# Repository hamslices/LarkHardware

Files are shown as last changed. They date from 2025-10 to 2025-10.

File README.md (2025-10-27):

# Lark - Thermal Print Engine Controller

**Version:** 01.00.01  
**Author:** HamSlices  
**License:** CERN Open Hardware Licence v2 - Strongly Reciprocal  

## This Design Still Needs Bench Tested, WIP, waiting on boards (10/27/2025)

This repository contains the complete hardware design files for the Lark, a controller board specifically designed for the **FUJITSU FTP-68EMCL112-R** 8-inch thermal print mechanism.

The goal of this project is to provide a fully open-source hardware solution for driving this excellent thermal printer, suitable for custom projects, prototyping, or integration into larger systems.

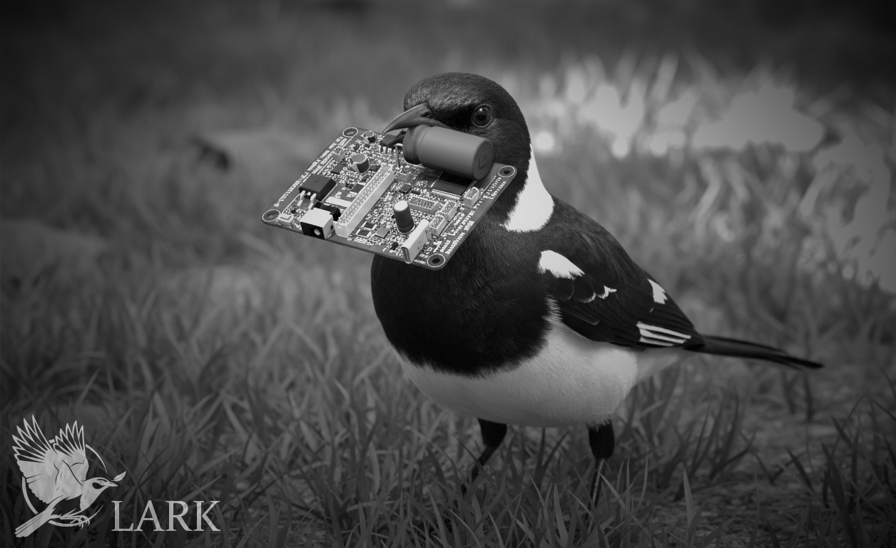
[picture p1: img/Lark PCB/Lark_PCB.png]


## Repository Contents

This repository includes all the necessary resources to build and case the hardware:

*   **Lark Controller Board**: The core of the project, designed to drive the Fujitsu thermal printer.
*   **Front I/O Board**: A separate PCB for user-facing controls and connectors.
*   **STLink-V2 Adapter**: A small adapter PCB to easily connect an STLink-V2 for programming and debugging.
*   **3D Printable Enclosures**: Includes custom cases for the Lark board, the Front I/O board, and a test enclosure for the print mechanism itself.

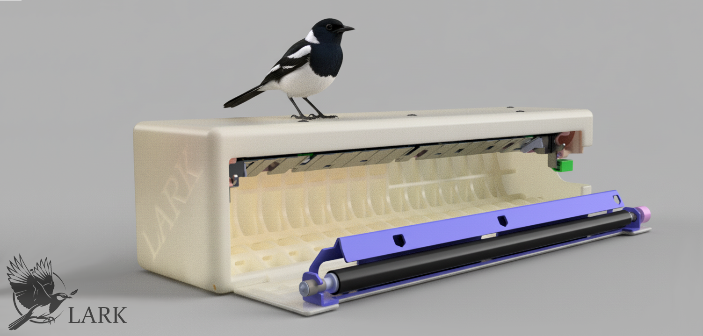
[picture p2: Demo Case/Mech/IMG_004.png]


## Directory Structure

Here is a breakdown of the repository's structure:

*   **`/3D`**: Contains 3D models of the various hardware components and enclosures.
*   **`/CubeMX_Lark`**: The STM32CubeMX project file (`.ioc`) for configuring the Lark's microcontroller.
*   **`/Demo Case`**: Files for the 3D printable enclosures for the Lark board, Front I/O, and the print mechanism.
*   **`/img`**: Images, screenshots, and logos related to the project.
*   **`/Kicad Project Files`**: The source files for all hardware designed in KiCad.
    *   **`/FrontIO`**: KiCad project for the Front I/O board.
    *   **`/Lark`**: KiCad project for the main Lark controller board.
    *   **`/STLink_adapter`**: KiCad project for the STLink-V2 adapter.
*   **`/lib`**: Custom KiCad schematic symbols and PCB footprints created for this project.
*   **`/Production_Files`**: Ready-to-manufacture files (Gerbers and BOMs) for all PCBs.

## Getting Started

To work with the hardware design files, you will need to install the latest version of [KiCad](https://www.kicad.org/).

The 3D models are provided in STEP format and can be viewed with any compatible software.

The production files located in the `/Production_Files` directory are ready to be sent to a PCB manufacturer for fabrication and assembly.

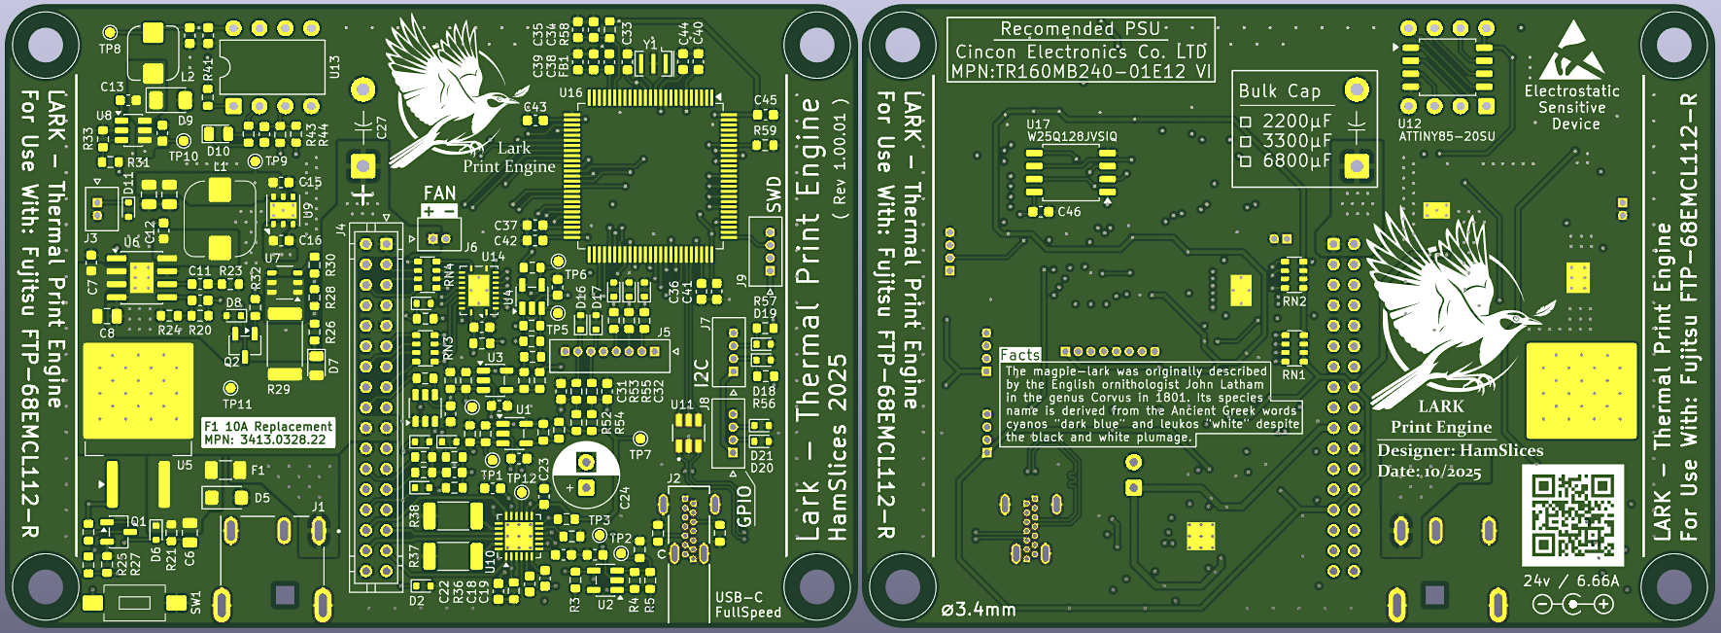
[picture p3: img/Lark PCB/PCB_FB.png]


## Software / Firmware

The firmware and software for the Lark controller is licensed under the **GPL v3** and is maintained in a separate repository.

## License

The hardware design files in this repository (schematics, PCB layouts, 3D models, etc.) are licensed under the **CERN Open Hardware Licence v2 - Strongly Reciprocal (CERN-OHL-S)**.

A full copy of the license is available in the `LICENSE` file in this repository. In essence, this license allows you to use, study, modify, and share the hardware designs, provided that you share any modifications or derivative works under the same license.

---
*Lark Print Engine © HamSlices 2025*

[The Lark Project](https://github.com/hamslices/The-Lark-Project)

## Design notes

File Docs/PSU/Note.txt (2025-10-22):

Durring testing I have found that the TR160MB240-01E12 VI
PSU will output 8.47A of continuous current before over current shutdown at > 8.5A

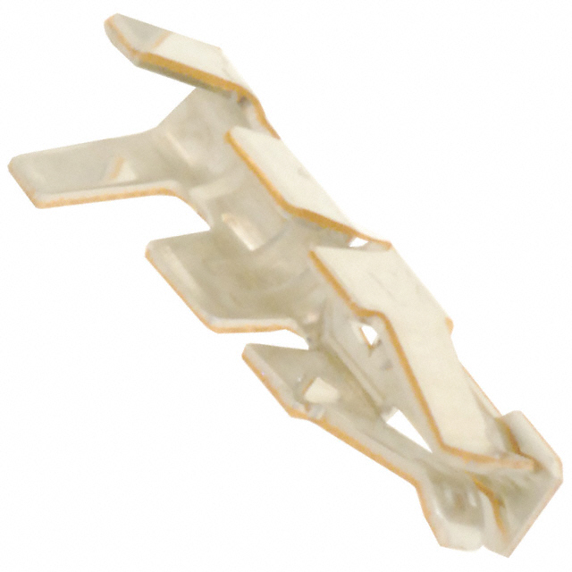
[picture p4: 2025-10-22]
Cable_Assy/img/SPHD-002T-P0.5.jpg

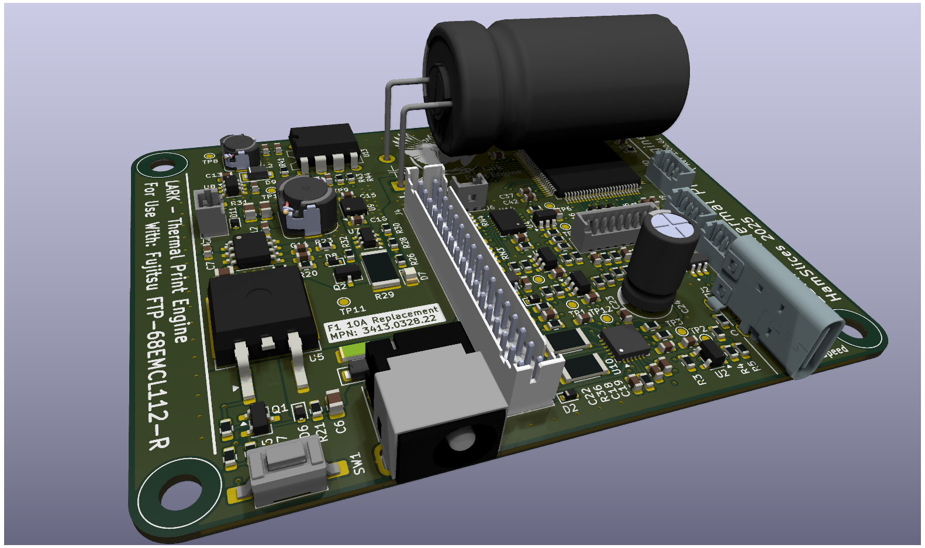
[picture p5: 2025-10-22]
img/Lark PCB/Lark_tilt.png

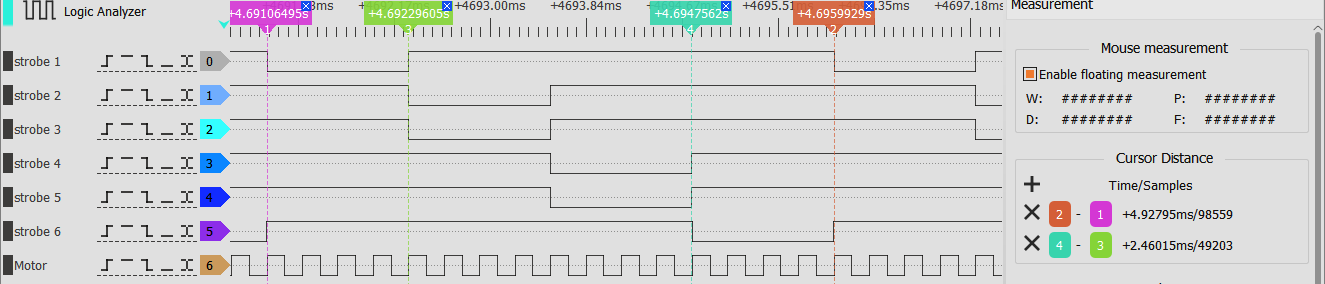
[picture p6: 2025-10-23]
img/scope/DSView-251023-170413.png

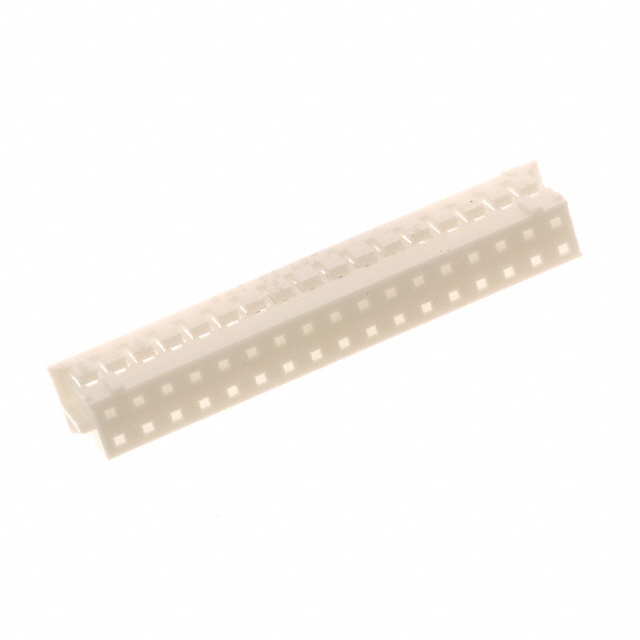
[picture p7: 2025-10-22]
Cable_Assy/img/PHDR-34VS.jpg

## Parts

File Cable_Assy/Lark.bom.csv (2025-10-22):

Id | Description | Qty | Unit | Designators | Manufacturer | MPN | Supplier | SPN
1 | Cable, 34 x 24 AWG, BK | 6 | in | W1 | CNC Tech | 3132-24-1-0500-001-1-TS | Digikey | CN119B-50-ND
2 | Connector, JST, PHDR-34VS, female, 34 pins | 2 |  | J1, X1 | JST | PHDR-34VS | Digikey | 455-1182-ND
3 | Crimp, CONN SOCKET 24-28AWG CRIMP TIN | 68 |  | J1, X1 | JST | SPHD-002T-P0.5 | Digikey | 455-1313CT-ND

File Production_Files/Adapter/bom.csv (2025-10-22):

Designator | Footprint | Quantity | Value | MPN
J1 | 0530470410 | 1 | 0530470410 | 0530470410
J2 | SFH11-PBPC-D10-ST-BK | 1 | SFH11-PBPC-D10-ST-BK | SFH11-PBPC-D10-ST-BK

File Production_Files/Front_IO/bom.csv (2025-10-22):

Designator | Footprint | Quantity | Value | MPN
D1 | QBLP600-RGB5-3164 | 1 | QBLP600-RGB5-3164 | QBLP600-RGB5-3164
J1 | 0530470810 | 1 | 0530470810 | 0530470810
J2 | 530470210 | 1 | 0530470210 | 0530470210
SW1, SW2, SW3 | TS04-66-65-BK-100-SMT | 3 | TS04-66-65-BK-100-SMT | TS04-66-65-BK-100-SMT

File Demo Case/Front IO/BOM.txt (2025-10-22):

2x,  MPN: 90116A151, URL: https://www.mcmaster.com/90116A151/

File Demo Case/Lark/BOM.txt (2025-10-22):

4x, MPN:  90116A155, URL: https://www.mcmaster.com/90116A155/

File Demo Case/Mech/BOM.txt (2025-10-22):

7x,  MPN: 90258A176, URL: https://www.mcmaster.com/90258A176/
1x, MPN: 88605K48, URL: https://www.mcmaster.com/88605K48/

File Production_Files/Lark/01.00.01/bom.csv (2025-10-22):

Designator | Footprint | Quantity | Value | MPN | DNP
C1, C12, C13, C18, C19, C2, C21, C22, C23, C25, C26, C28, C29, C3, C30, C31, C32, C33, C35, C39, C4, C40, C41, C42, C43, C44, C45, C46, C7 | C_0603 | 29 | 0.1µF | GRM188R72A104MA35J | C46
C10, C6, C8, C9 | C2012X5R1V226M125AC | 4 | 22µF | C2012X5R1V226M125AC
C11 | C_0603 | 1 | 6800pF | GRM1885C1H682JA01D
C14 | C_0603 | 1 | 4.7µF | GRM188R6YA475KE15D
C15, C16 | C_0603 | 2 | 10µF | GRM188R6YA106MA73D
C17 | C_0603 | 1 | 22µF | GRM188C61E226ME01J
C20 | C_0603 | 1 | 0.22µF | GRM188R71H224KAC4D
C24 | ECA-1VM101 | 1 | 100µF | ECA-1VM101
C27 | EEU-HD1V682_Right-Angle | 1 | 6800µF | EEU-HD1V682
C34, C38 | C_0603 | 2 | 1µF | GRM188D71H105KE01J
C36, C37 | C_0603 | 2 | 2.2µF | GRM188R61E225KA12J
C5 | C_0603 | 1 | 18pF | GRM1885C2E180JW07D
D1, D11, D12, D13, D14, D15, D16, D17, D18, D19, D2, D20, D21, D3, D4 | ESD5Z3.3T1G | 15 | ESD5Z3.3T1G | ESD5Z3.3T1G
D10, D7 | LED_0805 | 2 | LTST-C171GKT | LTST-C171GKT
D5 | SZSMF6L28AT3G | 1 | SZSMF6L28AT3G | SZSMF6L28AT3G
D6, D8 | BZT52C10T-7 | 2 | BZT52C15T-7 | BZT52C10T-7
D9 | SS26FL | 1 | SS26FL | SS26FL
F1 | 3413.0326.22 | 1 | 10A Slow Blow | 3413.0328.22
FB1 | MPZ1608S221ATA00 | 1 | 220 Ohms | MPZ1608S221ATA00
J1 | 54-00128 | 1 | 54-00128 | 54-00128
J2 | CONN_2169890002_MOL | 1 | 2169890002 | 2169890002
J3, J6 | 530470210 | 2 | 0530470210 | 0530470210
J4 | JST_PHD_B34B-PHDSS_2x17_P2.00mm_Vertical | 1 | B34B-PHDSS | B34B-PHDSS
J5 | 0530470810 | 1 | 0530470810 | 0530470810
J7, J8, J9 | 0530470410 | 3 | 0530470410 | 0530470410
L1 | CLF7045NIT-4R7N-D | 1 | 4.7µH | CLF7045NIT-4R7N-D
L2 | CLF5030NIT-150M-D | 1 | 15µH | CLF5030NIT-150M-D
Q1, Q2 | MMBT2222A-7-F | 2 | MMBT2222A-7-F | MMBT2222A-7-F
R1, R10, R16, R23, R33, R7 | R_0603 | 6 | 15kΩ | RMCF0603FG15K0
R11, R2, R5 | R_0603 | 3 | 220kΩ | RMCF0603FT220K
R12, R3 | R_0603 | 2 | 3kΩ | RMCF0603FT3K00
R13, R24, R27, R36, R4 | R_0603 | 5 | 100kΩ | RMCF0603FG100K
R14, R31 | R_0603 | 2 | 51kΩ | RMCF0603FT51K0
R15, R30, R50, R51, R6 | R_0603 | 5 | 100Ω | RMCF0603FG100R
R17, R8 | R_0603 | 2 | 24kΩ | RMCF0603FG24K0
R18 | R_0603 | 1 | 178kΩ | RMCF0603FT178K
R19, R58 | R_0603 | 2 | 0R | RMCF0603ZT0R00 | R19
R20 | R_0603 | 1 | 402kΩ | RMCF0603FT402K
R21, R26, R28, R34, R35, R41, R43, R45, R47, R52, R54, R59 | R_0603 | 12 | 10KΩ | RMCF0603FG10K0
R22 | R_0603 | 1 | 20KΩ | RMCF0603FG20K0
R25, R32, R42, R44, R46, R53, R55 | R_0603 | 7 | 1KΩ | RMCF0603FG1K00
R29 | R_2512 | 1 | 220Ω | RPCQ2512JT220R
R37, R38 | R_2010 | 2 | 400mΩ | CSRN2010FKR400
R39, R40 | R_0603 | 2 | 5.1KΩ | RMCF0603FT5K10
R48 | R_0603 | 1 | 33Ω | RMCF0603FT33R0
R49 | R_0603 | 1 | 280Ω | RMCF0603FT280R
R56, R57 | R_0603 | 2 | 4.7KΩ | RMCF0603FT4K70
R9 | R_0603 | 1 | 365kΩ | RMCF0603FT365K
RN1, RN2 | RAVF_164D | 2 | 10kΩ | RAVF164DJT10K0
RN3, RN4 | RAVF_164D | 2 | 33Ω | RAVF164DJT33R0
SW1 | PTS636 SP50 SMTR LFS | 1 | PTS636 SP50 SMTR LFS | PTS636 SP50 SMTR LFS
U1, U2, U3, U4 | SOT-23-5 | 4 | MIC7211YM5-TR | MIC7211YM5-TR
U10 | QFN-24-1EP_4x4mm_P0.5mm_EP2.75x2.75mm_ThermalVias | 1 | A4985SESTR-T | A4985SESTR-T
U11 | SOT95P280X145-6N | 1 | USBLC6-2SC6 | USBLC6-2SC6
U12 | 8-SOIC_5.3x8.2 | 1 | ATTINY85-20SU | ATTINY85-20SU | ATTINY85-20SU
U13 | DIP-8_W7.62mm | 1 | ATTINY85-20PU | ATTINY85-20PU
U14 | SN74LVC541ARGYR | 1 | SN74LVC541ARGYR | SN74LVC541ARGYR
U15 | SOT-23-6 | 1 | SN74LVC2G34DBVR | SN74LVC2G34DBVR
U16 | STM32H743VIT6 | 1 | STM32H743VIT6 | STM32H743VIT6
U17 | W25Q128JVSIQ | 1 | W25Q128JVSIQ | W25Q128JVSIQ | W25Q128JVSIQ
U5 | SQM120P06-07L_GE3 | 1 | SQM120P06-07L_GE3 | SQM120P06-07L_GE3
U6 | BD9E302EFJ-E2 | 1 | BD9E302EFJ-E2 | BD9E302EFJ-E2
U7 | SI3474DV-T1-BE3 | 1 | SI3474DV-T1-BE3 | SI3474DV-T1-BE3
U8 | BD9G102G-LBTR | 1 | BD9G102G-LBTR | BD9G102G-LBTR
U9 | LD39200PU33R | 1 | LD39200PU33R | LD39200PU33R
Y1 | CSTNE8M00G550000R0 | 1 | 8Mhz | CSTNE8M00G550000R0

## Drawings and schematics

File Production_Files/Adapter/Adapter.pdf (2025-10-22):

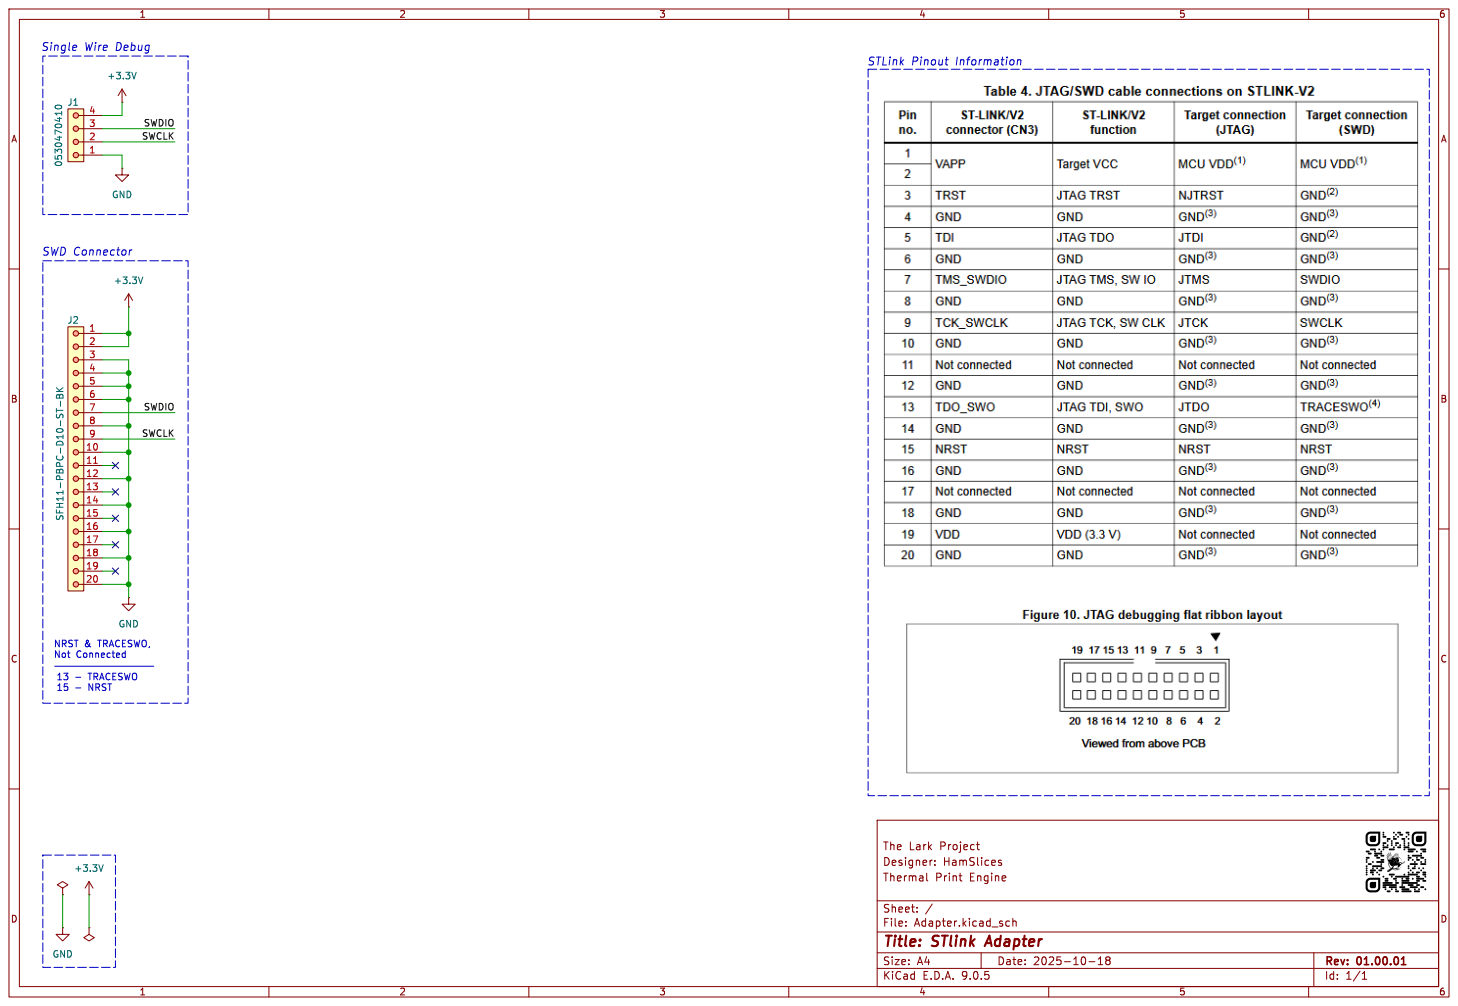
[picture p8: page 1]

15 - NRST NRST & TRACESWO, Not Connected

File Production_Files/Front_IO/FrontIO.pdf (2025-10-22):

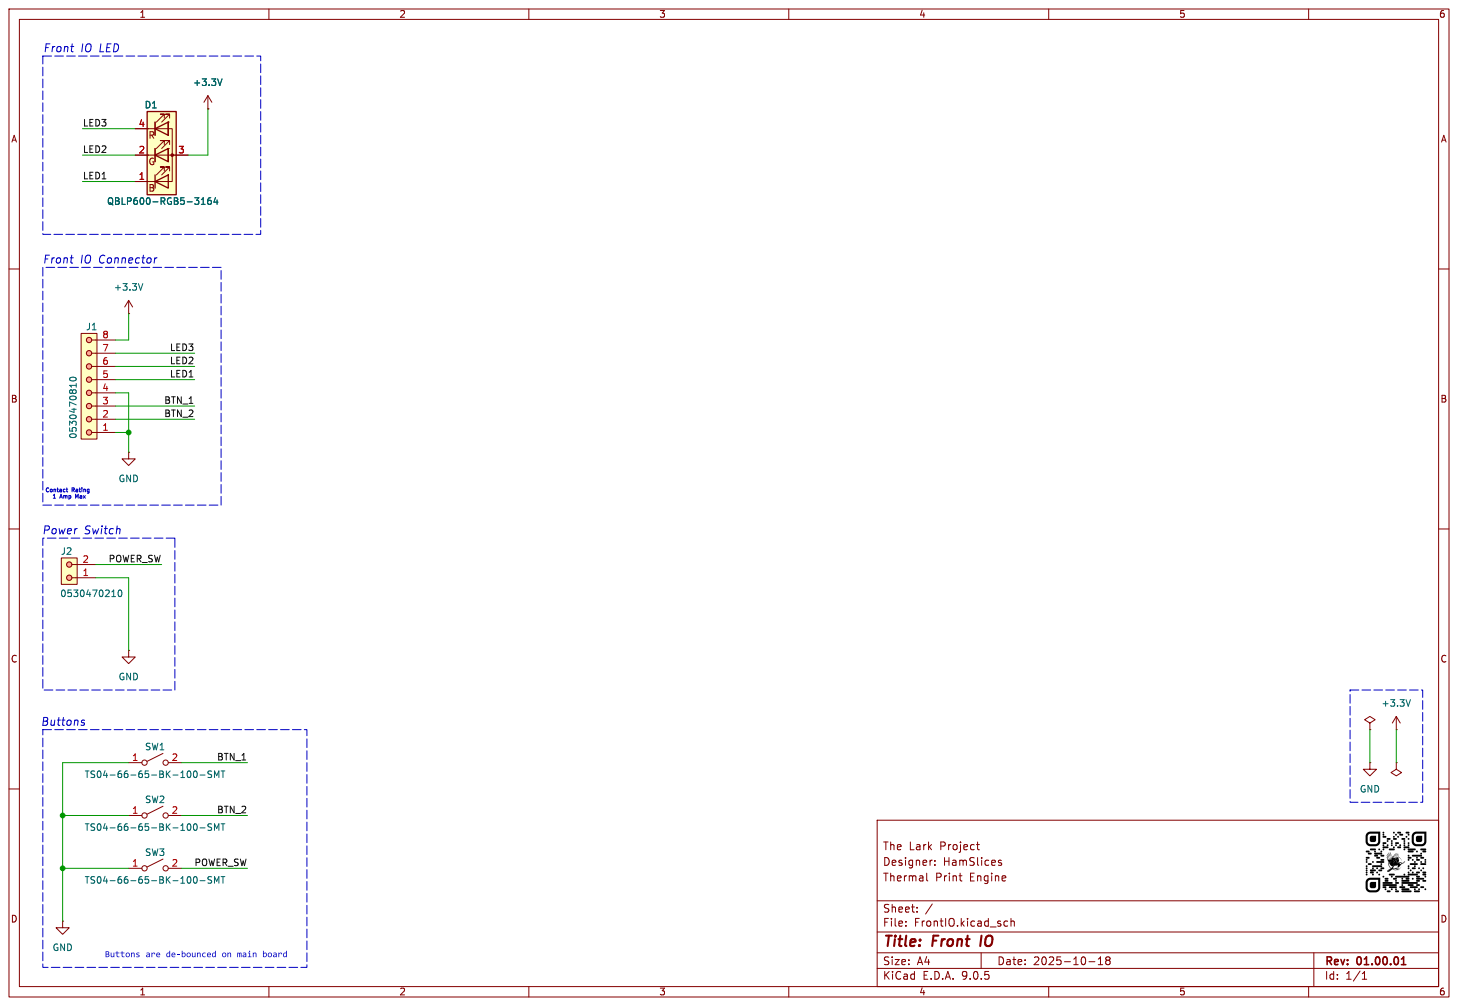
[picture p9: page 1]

Id: 1/1 Title: Front IO

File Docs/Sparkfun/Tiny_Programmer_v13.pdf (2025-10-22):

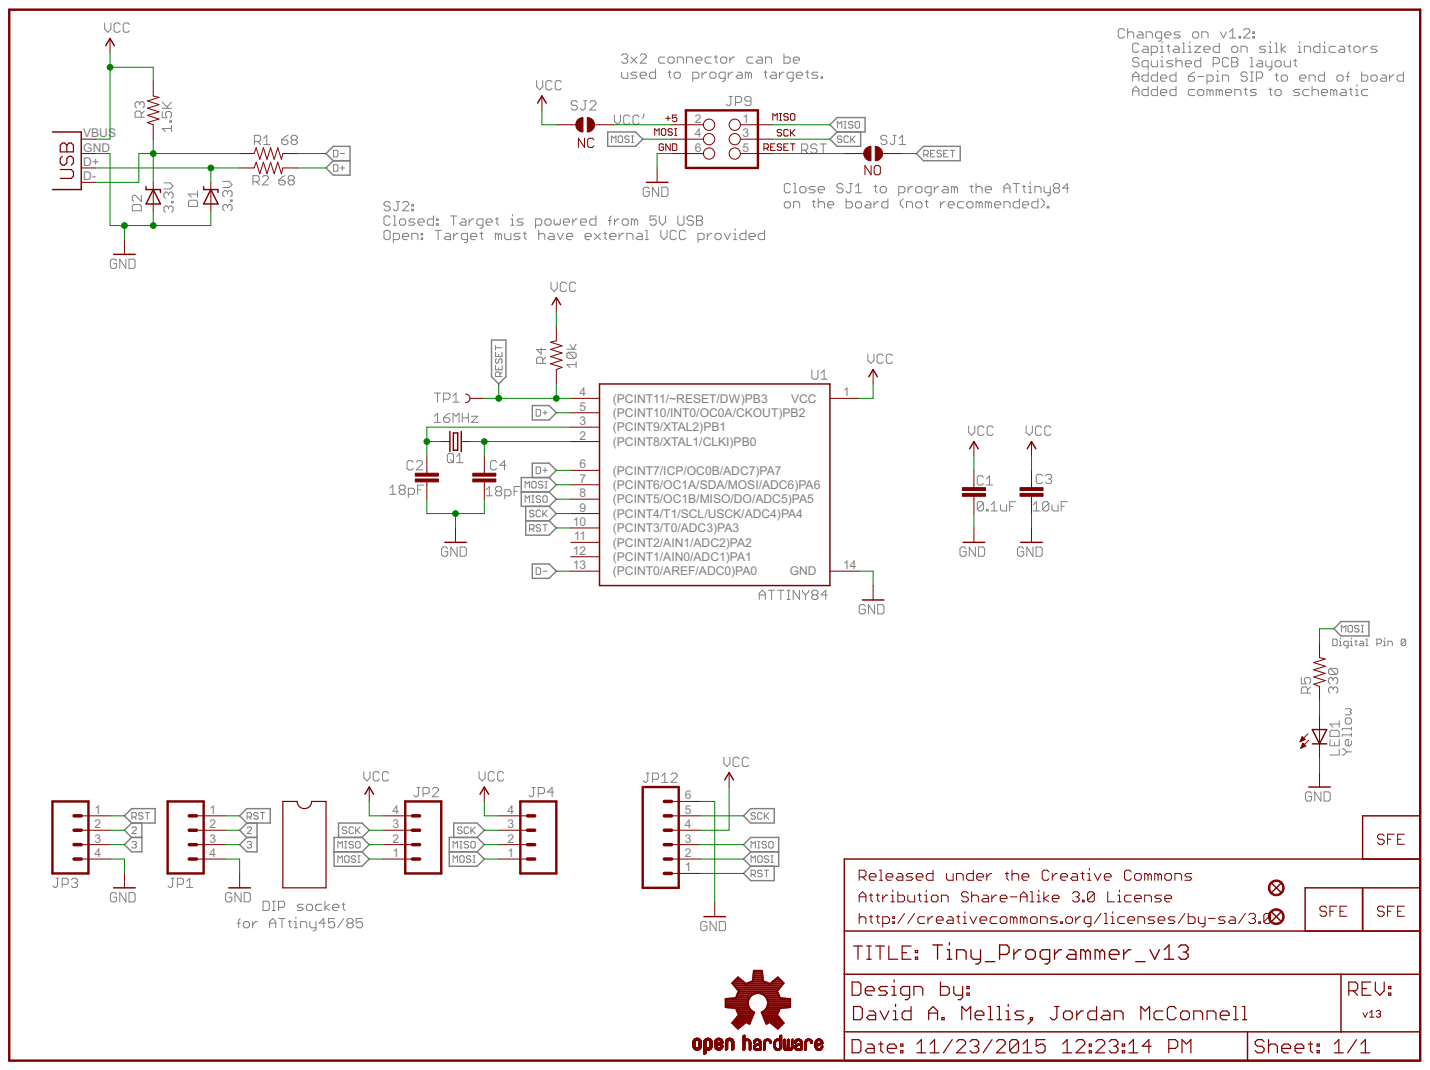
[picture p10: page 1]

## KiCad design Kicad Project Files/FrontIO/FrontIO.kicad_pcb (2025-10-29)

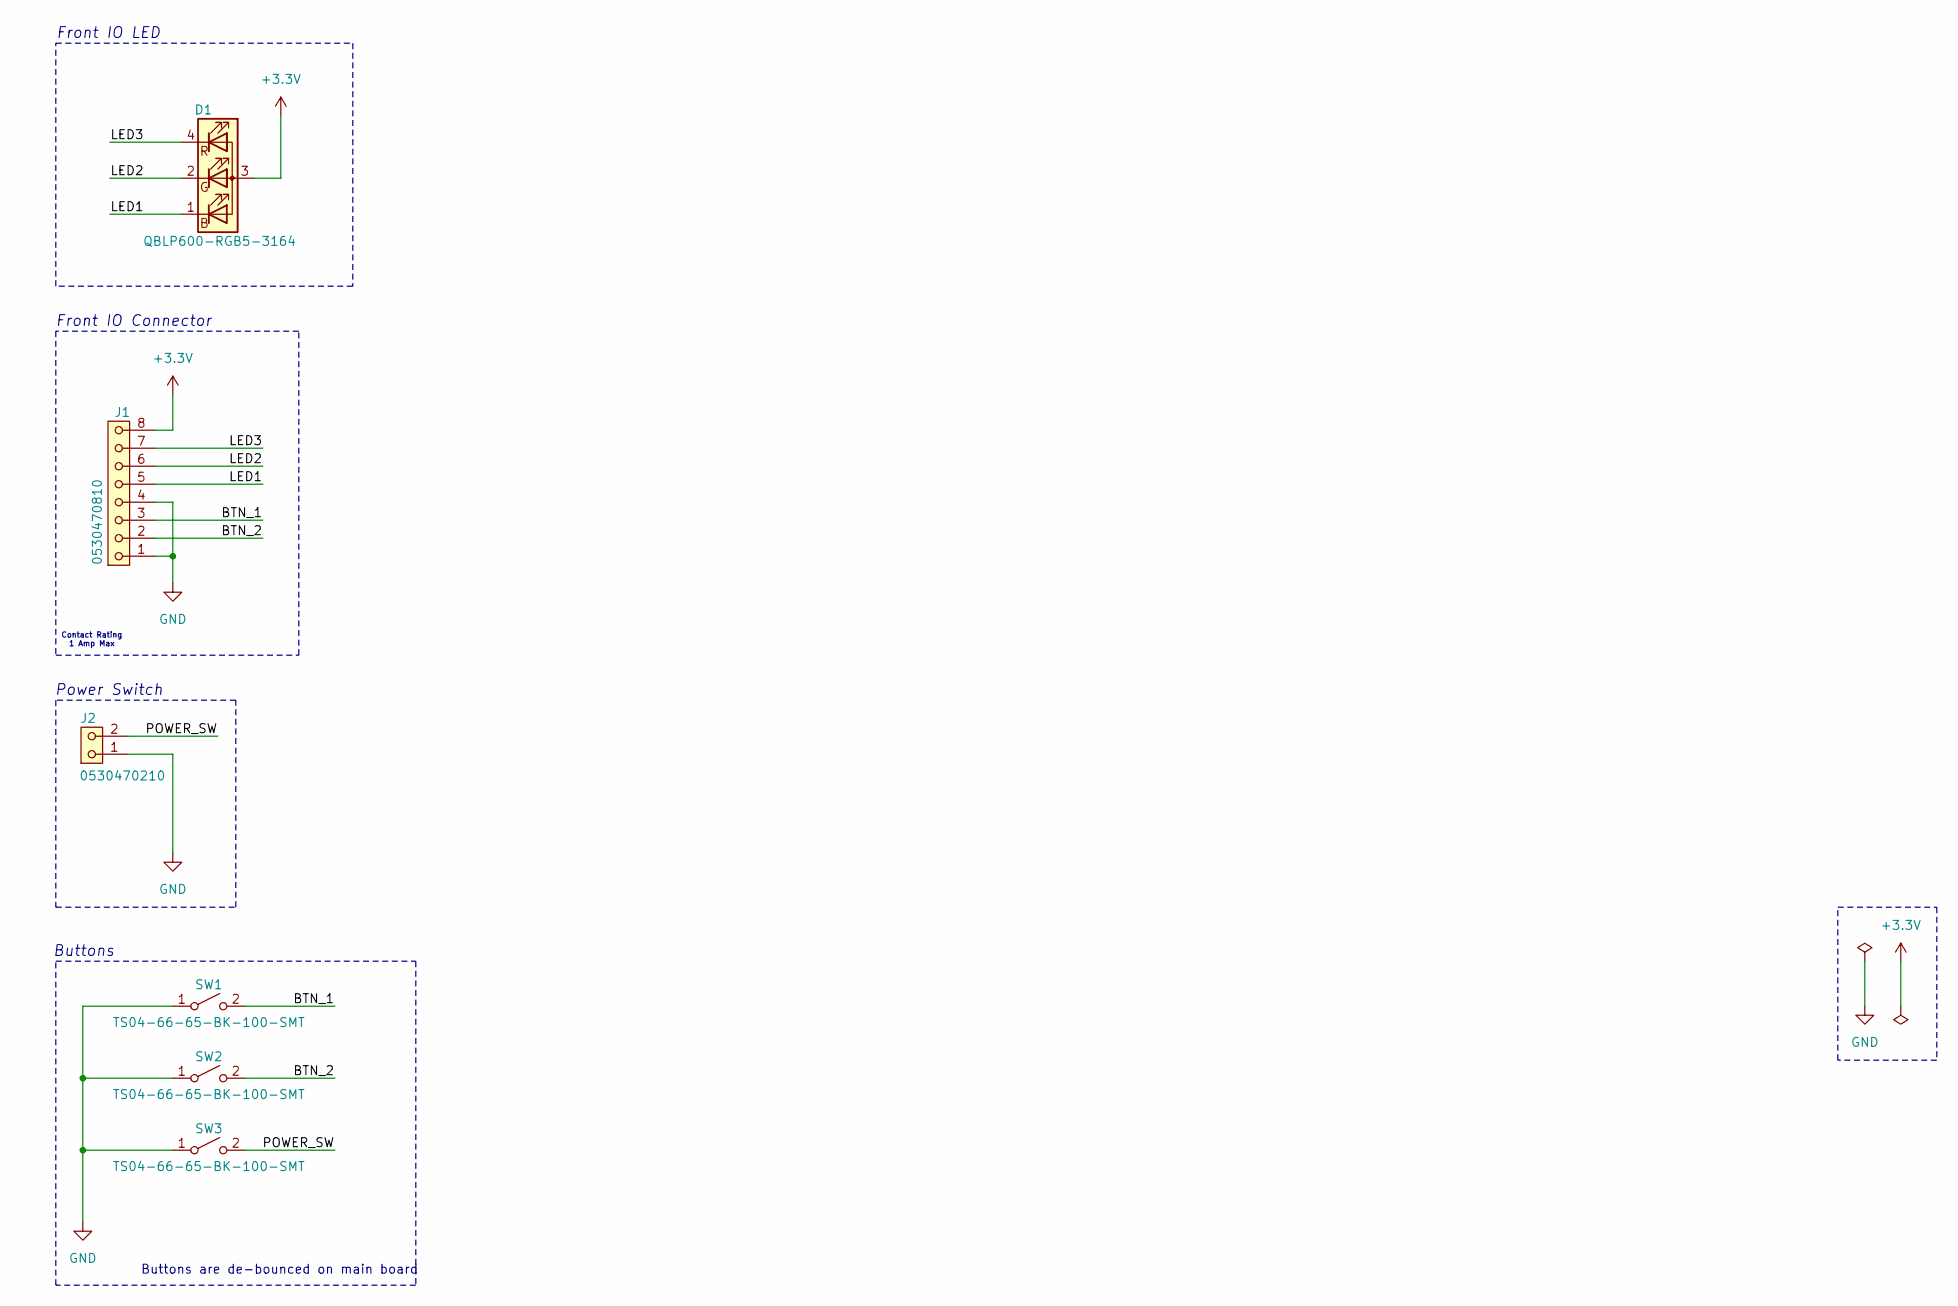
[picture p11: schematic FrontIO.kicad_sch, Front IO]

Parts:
D1: QBLP600-RGB5-3164; MPN QBLP600-RGB5-3164
J1: 0530470810; MPN 0530470810
J2: 0530470210; 530470210; MPN 0530470210
SW1, SW2, SW3: TS04-66-65-BK-100-SMT; MPN TS04-66-65-BK-100-SMT

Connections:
+3.3V: D1.3 (A), J1.8
/BTN_1: J1.3, SW1.2 (B), SW1.4 (B)
/BTN_2: J1.2, SW2.2 (B), SW2.4 (B)
/LED1: D1.1 (BK), J1.5
/LED2: D1.2 (GK), J1.6
/LED3: D1.4 (RK), J1.7
/POWER_SW: J2.2, SW3.2 (B), SW3.4 (B)
GND: J1.1, J1.4, J2.1, SW1.1 (A), SW1.3 (A), SW2.1 (A), SW2.3 (A), SW3.1 (A), SW3.3 (A)

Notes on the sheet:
Buttons are de-bounced on main board
Power Switch
Contact Rating 1 Amp Max
Buttons
Front IO Connector
Front IO LED

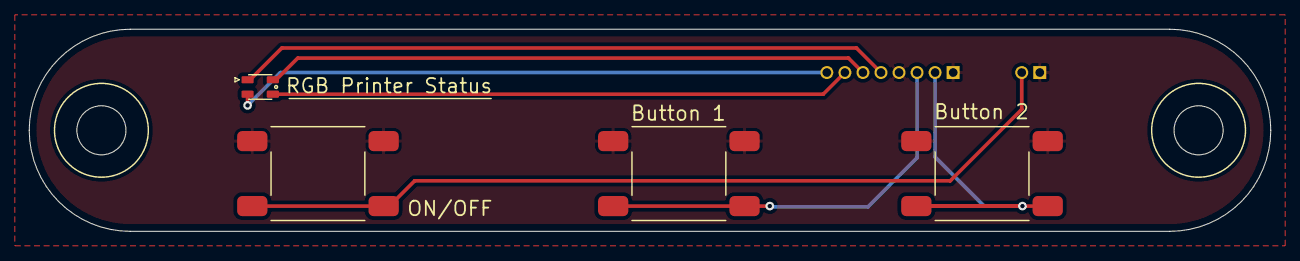
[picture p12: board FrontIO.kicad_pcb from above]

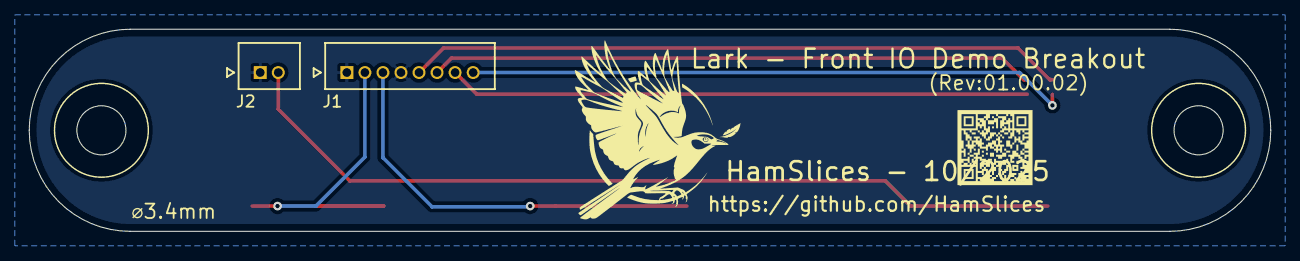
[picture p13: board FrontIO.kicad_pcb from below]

Board: 2 copper layers, 86.0 x 14.0 mm, 6 parts (2 on the bottom side), 8 nets.

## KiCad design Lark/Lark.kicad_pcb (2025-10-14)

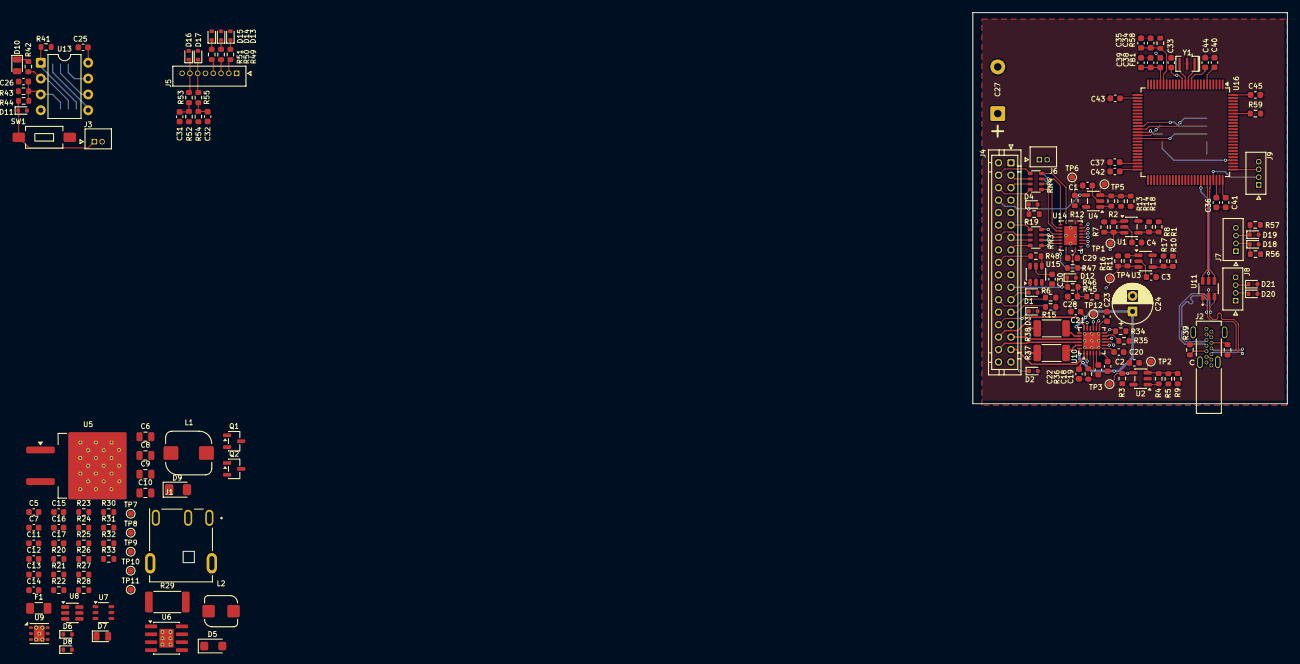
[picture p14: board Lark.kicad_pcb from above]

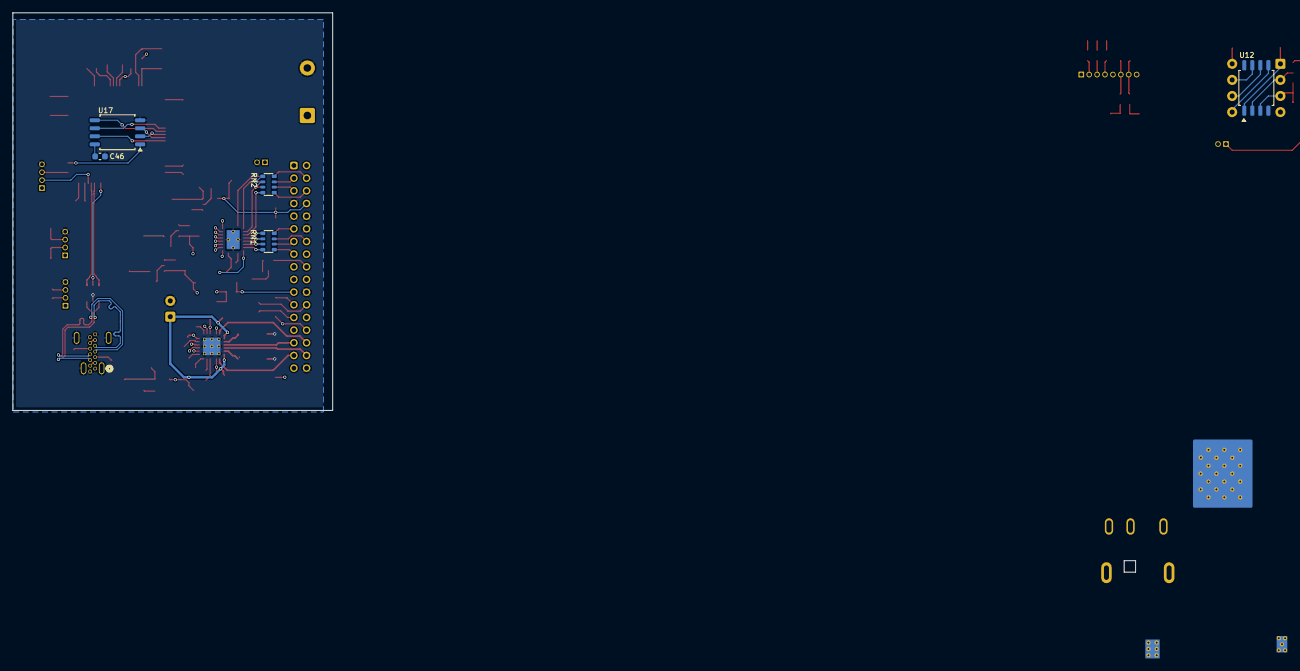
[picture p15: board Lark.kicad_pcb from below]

Board: 6 copper layers, 176 parts (5 on the bottom side), 118 nets.

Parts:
C1, C2, C3, C4, C7, C12, C13, C18, C19, C21, C22, C23, C25, C26, C28, C29, C30, C31, C32, C33, C35, C39, C40, C41, C42, C43, C44, C45, C46: 0.1µF; C_0603
C5: 18pF; C_0603
C6, C8, C9, C10: 22µF; C2012X5R1V226M125AC
C11: 6800pF; C_0603
C14: 4.7µF; C_0603
C15, C16: 10µF; C_0603
C17: 22µF; C_0603
C20: 0.22µF; C_0603
C24: 100µF; ECA-1VM101
C27: 6800µF; EEU-HD1V682_Right-Angle
C34, C38: 1µF; C_0603
C36, C37: 2.2µF; C_0603
D1, D2, D3, D4, D11, D12, D13, D14, D15, D16, D17, D18, D19, D20, D21: ESD5Z3.3T1G
D5: SZSMF6L28AT3G
D6, D8: BZT52C15T-7; BZT52C10T-7
D7, D10: LTST-C171GKT; LED_0805
D9: SS26FL
F1: 8A Slow Blow; 3413.0326.22
FB1: 220 Ohms; MPZ1608S221ATA00
J1: 54-00128
J2: 2169890002; CONN_2169890002_MOL
J3, J6: 0530470210; 530470210
J4: B34B-PHDSS; JST_PHD_B34B-PHDSS_2x17_P2.00mm_Vertical
J5: 0530470810
J7, J8, J9: 0530470410
L1: 4.7µH; CLF7045NIT-4R7N-D
L2: 15µH; CLF5030NIT-150M-D
Q1, Q2: MMBT2222A-7-F
R1, R7, R10, R16, R23, R33: 15kΩ; R_0603
R2, R5, R11: 220kΩ; R_0603
R3, R12: 3kΩ; R_0603
R4, R13, R24: 100kΩ; R_0603
R6, R15, R30, R50, R51: 100Ω; R_0603
R8, R17: 24kΩ; R_0603
R9: 365kΩ; R_0603
R14, R31: 51kΩ; R_0603
R18: 178kΩ; R_0603
R19, R58: 0R; R_0603
R20: 402kΩ; R_0603
R21, R26, R28, R34, R35, R41, R43, R45, R47, R52, R54, R59: 10KΩ; R_0603
R22: 20KΩ; R_0603
R25, R32, R42, R44, R46, R53, R55: 1KΩ; R_0603
R27, R36: 100KΩ; R_0603
R29: 220Ω; R_2512
R37, R38: 400mΩ; R_2010
R39, R40: 5.1KΩ; R_0603
R48: 33Ω; R_0603
R49: 280Ω; R_0603
R56, R57: 4.7KΩ; R_0603
RN1, RN2: 10kΩ; RAVF_164D
RN3, RN4: 33Ω; RAVF_164D
SW1: PTS636 SP50 SMTR LFS
TP1, TP2, TP3, TP4, TP5, TP6, TP7, TP8, TP9, TP10, TP11, TP12: TestPoint; TestPoint_Pad_D1.0mm
U1, U2, U3, U4: MIC7211YM5-TR; SOT-23-5
U5: SQM120P06-07L_GE3
U6: BD9E302EFJ-E2
U7: SI3474DV-T1-BE3
U8: BD9G102G-LBTR
U9: LD39200PU33R
U10: A4985SESTR-T; QFN-24-1EP_4x4mm_P0.5mm_EP2.75x2.75mm_ThermalVias
U11: USBLC6-2SC6; SOT95P280X145-6N
U12: ATTINY85-20SU; 8-SOIC_5.3x8.2
U13: ATTINY85-20PU; DIP-8_W7.62mm
U14: SN74LVC541ARGYR
U15: SN74LVC2G34DBVR; SOT-23-6
U16: STM32H743VIT6
U17: W25Q128JVSIQ
Y1: 8Mhz; CSTNE8M00G550000R0

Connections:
+3.3V: C1.2, C2.2, C3.2, C4.2, C16.1, C23.1, C29.1, C30.1, C40.1, C41.1, C42.1, C43.1, C44.1, C45.1, C46.2, FB1.1, J4.16, J4.26, J4.27, J5.1, J7.1, J8.1, J9.1, R1.1, R3.1, R5.1, R10.1, R12.1, R14.1, R34.1, R45.1, R47.1, R52.1, R54.1, R56.1, R57.1, R58.1, RN1.5 (R4.2), RN1.6 (R3.2), RN1.7 (R2.2), RN1.8 (R1.2), RN2.5 (R4.2), RN2.6 (R3.2), RN2.7 (R2.2), RN2.8 (R1.2), TP7.1, U1.2 (V+), U2.2 (V+), U3.2 (V+), U4.2 (V+), U9.1 (OUT), U9.2 (SENSE), U10.13 (VDD), U14.20 (VCC), U15.5 (VCC), U16.6 (VBAT), U16.11 (VDD), U16.27 (VDD), U16.50 (VDD), U16.75 (VDD), U16.100 (VDD), U17.8 (VCC)
+3.3VBC: C17.1, C25.1, D10.2 (A), L2.2, R31.1, R41.1, R43.1, TP8.1, U12.8 (VCC), U13.8 (VCC)
+4V: C5.2, C9.1, C10.1, C15.1, L1.1, R20.1, TP9.1, U9.5 (EN), U9.6 (IN)
+5V: J2.A4 (VBUS), J2.A9 (VBUS), J2.B4 (VBUS), J2.B9 (VBUS), U11.5, U16.68 (PA9)
+24V: C7.2, C8.1, C19.1, C21.1, C22.1, C24.1, C27.1, D7.2 (A), J4.1, J4.2, J4.19, J4.20, J6.1, R29.1, TP11.1, U5.2 (D), U6.2 (VIN), U6.3 (EN), U10.19 (VBB1), U10.24 (VBB2)
+24VBC: C6.1, C14.1, D5.1 (Cathode), D6.1 (K), F1.2, R21.1, R28.1, TP10.1, U5.3 (S), U8.4 (EN), U8.5 (VCC)
/Auxiliary/GPIOA: D20.1 (Cathode), J8.2
/Auxiliary/GPIOB: D21.1 (Cathode), J8.3
/Auxiliary/SCL: D19.1 (Cathode), J7.3, R57.2, U16.92 (PB6)
/Auxiliary/SDA: D18.1 (Cathode), J7.2, R56.2, U16.93 (PB7)
/Boot Controller/IO3: R42.2, U12.2 (PB3), U13.2 (PB3)
/Boot Controller/IO4: C26.1, R43.2, R44.2, U12.3 (PB4), U13.3 (PB4)
/Boot Controller/MCURST: R41.2, U12.1 (PB5), U13.1 (PB5)
/Boot Controller/POWER_SW: D11.1 (Cathode), J3.1, R44.1, SW1.2 (B)
/FTP-68EMCL Connector/Buffers/Y1: RN1.4 (R4.1), RN3.1 (R1.1), U14.18 (Y1)
/FTP-68EMCL Connector/Buffers/Y2: RN1.3 (R3.1), RN3.2 (R2.1), U14.17 (Y2)
/FTP-68EMCL Connector/Buffers/Y3: RN1.2 (R2.1), RN3.3 (R3.1), U14.16 (Y3)
/FTP-68EMCL Connector/Buffers/Y4: RN1.1 (R1.1), RN3.4 (R4.1), U14.15 (Y4)
/FTP-68EMCL Connector/Buffers/Y5: RN2.4 (R4.1), RN4.1 (R1.1), U14.14 (Y5)
/FTP-68EMCL Connector/Buffers/Y6: RN2.2 (R2.1), RN4.2 (R2.1), U14.13 (Y6)
/FTP-68EMCL Connector/Buffers/Y7: RN2.1 (R1.1), RN4.3 (R3.1), U14.12 (Y7)
/FTP-68EMCL Connector/Buffers/Y8: RN4.4 (R4.1), U14.11 (Y8)
/FTP-68EMCL Connector/Buffers/Y9: R48.2, U15.4 (Y2)
/FTP-68EMCL Connector/CLK: U14.2 (A1), U16.29 (PA5)
/FTP-68EMCL Connector/CLOCK: J4.15, RN3.8 (R1.2)
/FTP-68EMCL Connector/DATA: J4.4, RN4.5 (R4.2)
/FTP-68EMCL Connector/DIN: U14.9 (A8), U16.31 (PA7)
/FTP-68EMCL Connector/HUP: C28.1, R45.2, R46.1
/FTP-68EMCL Connector/MTA: J4.32, U10.22 (OUT2A)
/FTP-68EMCL Connector/MTB: J4.29, U10.21 (OUT1A)
/FTP-68EMCL Connector/MT/A: J4.31, U10.1 (OUT2B)
/FTP-68EMCL Connector/MT/B: J4.30, U10.18 (OUT1B)
/FTP-68EMCL Connector/PHK_M: J4.24, R6.1
/FTP-68EMCL Connector/PHK_P: J4.25, R15.1
/FTP-68EMCL Connector/SW1: D12.1 (Cathode), J4.21, R46.2
/FTP-68EMCL Connector//LATCH: J4.18, R48.1
/FTP-68EMCL Connector//OE: R47.2, U14.1 (/OE1), U14.19 (/OE2)
/FTP-68EMCL Connector//STROBE_1: J4.13, RN3.7 (R2.2)
/FTP-68EMCL Connector//STROBE_2: J4.14, RN3.6 (R3.2)
/FTP-68EMCL Connector//STROBE_3: J4.11, RN3.5 (R4.2)
/FTP-68EMCL Connector//STROBE_4: J4.5, RN4.7 (R2.2)
/FTP-68EMCL Connector//STROBE_5: J4.6, RN4.8 (R1.2)
/FTP-68EMCL Connector//STROBE_6: J4.3, RN4.6 (R3.2)
/FrontIO/BTN1: C32.1, R54.2, R55.1
/FrontIO/BTN2: C31.1, R52.2, R53.1
/FrontIO/BTN_1: D17.1 (Cathode), J5.6, R55.2
/FrontIO/BTN_2: D16.1 (Cathode), J5.7, R53.2
/FrontIO/LED1: J5.4, R51.1
/FrontIO/LED2: J5.3, R50.1
/FrontIO/LED3: J5.2, R49.1
/FrontIO/PWM1: D15.1 (Cathode), R51.2, U16.63 (PC6)
/FrontIO/PWM2: D14.1 (Cathode), R50.2, U16.64 (PC7)
/FrontIO/PWM3: D13.1 (Cathode), R49.2, U16.65 (PC8)
/MCU/ADC_CH1: R19.1, U16.91 (PB5)
/MCU/BOOT0: R59.1, U12.7 (PB2), U13.7 (PB2), U16.94 (BOOT0)
/MCU/H_TMP: R13.1, U4.1
/MCU/MARK: R2.1, U1.1
/MCU/M_TMP: R4.1, U2.1
/MCU/NRST: C33.1, U12.6 (PB1), U13.6 (PB1), U16.14 (NRST)
/MCU/OSC_IN: U16.12 (PH0), Y1.1
/MCU/OSC_OUT: U16.13 (PH1), Y1.3
/MCU/PAPER: R11.1, U3.1
/MCU/QSPI_CLK: U16.36 (PB2), U17.6 (CLK)
/MCU/QSPI_IO0: U16.37 (PE7), U17.5 (DI/IO_{0})
/MCU/QSPI_IO1: U16.38 (PE8), U17.2 (DO/IO_{1})
/MCU/QSPI_IO2: U16.39 (PE9), U17.3 (~WP/IO_{2})
/MCU/QSPI_IO3: U16.40 (PE10), U17.7 (~HOLD/~RESET/IO_{3})
/MCU/QSPI_NCS: U16.79 (PC11), U17.1 (~CS)
/MCU/SWCLK: J9.3, U16.76 (PA14)
/MCU/SWDIO: J9.2, U16.72 (PA13)
/MCU/VCAP1: C37.1, U16.48 (VCAP)
/MCU/VCAP2: C36.1, U16.73 (VCAP)
/MCU/VDDA: C38.1, C39.1, FB1.2, U16.21 (VDDA)
/MCU/VREF: C34.1, C35.1, R58.2, U16.20 (VREF+)
/MCU//SLEEP: R34.2, U10.12 (/SLEEP)
/Motor Driver/CP1: C18.1, U10.4 (CP1)
/Motor Driver/CP2: C18.2, U10.5 (CP2)
/Motor Driver/ROSC: R35.1, U10.11 (ROSC)
/Motor Driver/SENSE1: R38.1, U10.20 (SENSE1)
/Motor Driver/SENSE2: R37.1, U10.23 (SENSE2)
/Motor Driver/VCP: C19.2, U10.6 (VCP)
/Motor Driver/VREF: TP12.1, U10.15 (REF), U16.28 (PA4)
/Motor Driver/VREG: C20.1, U10.7 (VREG)
/Motor Driver//EN: R36.1, U10.2 (/EN)
/Power/BOOT: C12.1, U6.1 (BOOT)
/Power/COMP: C11.2, U6.6 (COMP)
/Power/FB_1: R31.2, R33.1, U8.3 (FB)
/Power/FB_2: C5.1, R20.2, R24.1, U6.5 (FB)
/Power/PWR_EN: R25.1, R27.1, R32.1, U12.5 (PB0), U13.5 (PB0)
/Power/SW: C12.2, L1.2, U6.8 (SW)
/Sensors/HTMP: D4.1 (Cathode), J4.8, R12.2, R19.2, TP6.1, U4.4 (-)
/Sensors/MTMP: D2.1 (Cathode), J4.33, R3.2, TP3.1, U2.4 (-)
/Sensors/PHE_M: D1.1 (Cathode), J4.23, R2.2, R7.1, TP1.1, U1.3 (+)
/Sensors/PHE_P: D3.1 (Cathode), J4.28, R11.2, R16.1, TP4.1, U3.3 (+)
/USB/CC1: J2.A5 (CC1), R39.1
/USB/CC2: J2.B5 (CC2), R40.1
/USB/D+: U11.4, U16.71 (PA12)
/USB/D-: U11.6, U16.70 (PA11)
/USB/USB_N: J2.A7 (D-), J2.B7 (D-), U11.1
/USB/USB_P: J2.A6 (D+), J2.B6 (D+), U11.3
GND: C1.1, C2.1, C3.1, C4.1, C7.1, C8.2, C9.2, C10.2, C14.2, C15.2, C16.2, C17.2, C20.2, C21.2, C22.2, C23.2, C24.2, C25.2, C26.2, C27.2, C28.2, C29.2, C30.2, C31.2, C32.2, C33.2, C34.2, C35.2, C36.2, C37.2, C38.2, C39.2, C40.2, C41.2, C42.2, C43.2, C44.2, C45.2, C46.1, D1.2 (Anode), D2.2 (Anode), D3.2 (Anode), D4.2 (Anode), D5.2 (Anode), D8.2 (A), D9.2 (A), D11.2 (Anode), D12.2 (Anode), D13.2 (Anode), D14.2 (Anode), D15.2 (Anode), D16.2 (Anode), D17.2 (Anode), D18.2 (Anode), D19.2 (Anode), D20.2 (Anode), D21.2 (Anode), J1.2, J1.SH1, J1.SH2, J2.A1 (GND), J2.A12 (GND), J2.B1 (GND), J2.B12 (GND), J2.S1 (SHIELD), J3.2, J4.7, J4.9, J4.10, J4.12, J4.22, J4.34, J5.5, J5.8, J6.2, J7.4, J8.4, J9.4, Q1.2 (E), Q2.2 (E), R6.2, R7.2, R8.2, R9.2, R15.2, R16.2, R17.2, R18.2, R23.2, R24.2, R26.2, R27.2, R33.2, R35.2, R36.2, R37.2, R38.2, R39.2, R40.2, R59.2, SW1.1 (A), U1.5 (V-), U2.5 (V-), U3.5 (V-), U4.5 (V-), U6.4 (AGND), U6.7 (PGND), U6.9 (EP), U7.4 (S), U8.2 (GND), U9.3 (GND), U9.7 (EP), U10.3 (GND1), U10.16 (GND2), U10.25 (EP), U11.2, U12.4 (GND), U13.4 (GND), U14.10 (GND), U14.21 (EP), U15.1 (A1), U15.2 (GND), U16.10 (VSS), U16.19 (VSSA), U16.26 (VSS), U16.49 (VSS), U16.74 (VSS), U16.99 (VSS), U17.4 (GND), Y1.2
unnamed: C11.1, R23.1
unnamed: C6.2, D6.2 (A), R21.2, R22.1, U5.1 (G)
unnamed: D7.1 (K), R26.1
unnamed: D8.1 (K), Q2.3 (C), R28.2, R30.1
unnamed: C13.2, D9.1 (K), L2.1, U8.6 (LX)
unnamed: D10.1 (K), R42.1
unnamed: F1.1, J1.1
unnamed: Q1.1 (B), R25.2
unnamed: Q1.3 (C), R22.2
unnamed: Q2.1 (B), R32.2
unnamed: R1.2, R8.1, U1.4 (-)
unnamed: R4.2, R5.2, R9.1, TP2.1, U2.3 (+)
unnamed: R10.2, R17.1, U3.4 (-)
unnamed: R13.2, R14.2, R18.1, TP5.1, U4.3 (+)
unnamed: R29.2, U7.1 (D1), U7.2 (D2), U7.5 (D3), U7.6 (D4)
unnamed: R30.2, U7.3 (G)
unnamed: C13.1, U8.1 (BST)

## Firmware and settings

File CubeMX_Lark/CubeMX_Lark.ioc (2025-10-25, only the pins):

Mcu.UserName=STM32H743VITx
PA10.GPIO_Label=n_RST
PA10.Signal=GPIO_Output
PA11.Signal=USB_OTG_FS_DM
PA12.Signal=USB_OTG_FS_DP
PA3.Signal=ADCx_INP15
PA4.Signal=COMP_DAC11_group
PA5.Signal=SPI1_SCK
PA7.Signal=SPI1_MOSI
PA8.GPIO_Label=External_GPIO_B
PA8.Signal=GPIO_Output
PA9.Signal=USB_OTG_FS_VBUS
PB0.GPIO_Label=PAPER
PB0.Signal=GPIO_Input
PB1.GPIO_Label=n_OE
PB1.Signal=GPIO_Output
PB10.GPIO_Label=n_SLEEP
PB10.Signal=GPIO_Output
PB14.GPIO_Label=BTN2
PB14.Signal=GPIO_Input
PB15.GPIO_Label=BTN1
PB15.Signal=GPIO_Input
PB2.Signal=QUADSPI_CLK
PB6.Signal=I2C1_SCL
PB7.Signal=I2C1_SDA
PC11.Signal=QUADSPI_BK2_NCS
PC4.GPIO_Label=n_LAT
PC4.Signal=GPIO_Output
PC5.GPIO_Label=HUP
PC5.Signal=GPIO_Input
PC6.Signal=S_TIM8_CH1
PC7.Signal=S_TIM8_CH2
PC8.Signal=S_TIM8_CH3
PC9.GPIO_Label=External_GPIO_A
PC9.Signal=GPIO_Output
PD1.GPIO_Label=n_EN
PD1.Signal=GPIO_Output
PD10.GPIO_Label=n_STB5
PD10.Signal=GPIO_Output
PD11.GPIO_Label=n_STB3
PD11.Signal=GPIO_Output
PD12.GPIO_Label=n_STB2
PD12.Signal=GPIO_Output
PD13.GPIO_Label=n_STB1
PD13.Signal=GPIO_Output
PD3.GPIO_Label=M_TMP
PD3.Signal=GPIO_Input
PD5.GPIO_Label=MS1
PD5.Signal=GPIO_Output
PD7.GPIO_Label=MS2
PD7.Signal=GPIO_Output
PD8.GPIO_Label=n_STB6
PD8.Signal=GPIO_Output
PD9.GPIO_Label=n_STB4
PD9.Signal=GPIO_Output
PE10.Signal=QUADSPI_BK2_IO3
PE11.GPIO_Label=MARK
PE11.Signal=GPIO_Input
PE12.GPIO_Label=H_TMP
PE12.Signal=GPIO_Input
PE14.GPIO_Label=DIR
PE14.Signal=GPIO_Output
PE15.GPIO_Label=STEP
PE15.Signal=GPIO_Output
PE7.Signal=QUADSPI_BK2_IO0
PE8.Signal=QUADSPI_BK2_IO1
PE9.Signal=QUADSPI_BK2_IO2

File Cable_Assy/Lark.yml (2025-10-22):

connectors:
  J1:
    pincount: 34
    pinlabels: [VH, VH, /STB6, DI, /STB4, /STB5, GND, HTMP, GND, GND, /STB3, GND, /STB1, /STB2, CLK, VDD, DO, /LAT, VH, VH, SW, GND, PHE, PHK, PHK, VSEN, VSEN, PHE, MT_B, MT_/B, MT_/A, MT_A, MTMP, GND]
    type: JST, PHDR-34VS
    subtype: female
    manufacturer: '<a href="https://www.jst.com/">JST</a>'
    mpn: PHDR-34VS
    supplier: '<a href="https://www.digikey.com/">Digikey</a>'
    spn: 455-1182-ND
    image:
      src: ./img/PHDR-34VS.jpg
      width: 200       # range: 1~65535; unit: points
      height: 200      # range: 1~65535; unit: points
    # add a list of additional components to a part (shown in graph)
    additional_components:
      - type: Crimp # short identifier used in graph
        subtype: CONN SOCKET 24-28AWG CRIMP TIN # extra information added to type in bom
        qty_multiplier: populated # multipier for quantity (number of populated pins)
        manufacturer: '<a href="https://www.jst.com/">JST</a>'
        mpn: SPHD-002T-P0.5 # set manufacturer part number
        supplier: '<a href="https://www.digikey.com/">Digikey</a>'
        spn: 455-1313CT-ND
  X1:
    pincount: 34
    pinlabels: [MTMP, GND, MT_/A, MT_A, MT_B, MT_/B, VSEN, PHE, PHK, VSEN, PHE, PHK, SW, GND, VH, VH, DO, /LAT, CLK, VDD, /STB1, /STB2, /STB3, GND, GND, GND, GND, HTMP, /STB4, /STB5, /STB6, DI, VH, VH]
    type: JST, PHDR-34VS
    subtype: female
    manufacturer: '<a href="https://www.jst.com/">JST</a>'
    mpn: PHDR-34VS
    supplier: '<a href="https://www.digikey.com/">Digikey</a>'
    spn: 455-1182-ND
    image:
      src: ./img/PHDR-34VS.jpg
      width: 200       # range: 1~65535; unit: points
      height: 200      # range: 1~65535; unit: points    
    # add a list of additional components to a part (shown in graph)
    additional_components:
      - type: Crimp # short identifier used in graph
        subtype: CONN SOCKET 24-28AWG CRIMP TIN # extra information added to type in bom
        qty_multiplier: populated # multipier for quantity (number of populated pins)
        manufacturer: '<a href="https://www.jst.com/">JST</a>'
        mpn: SPHD-002T-P0.5 # set manufacturer part number
        supplier: '<a href="https://www.digikey.com/">Digikey</a>'
        spn: 455-1313CT-ND

cables:
  W1:
    wirecount: 34
    length: 6 in
    gauge: 24 AWG
    # colors: [BK,BK,BK,BK,BK,BK,BK,BK,BK,BK,BK,BK,BK,BK,BK,BK,BK,BK,BK,BK,BK,BK,BK,BK,BK,BK,BK,BK,BK,BK,BK,BK,BK,BK] # color = BLACK
    color: BK
    manufacturer: '<a href="https://www.cnctech.us/">CNC Tech</a>'
    mpn: 3132-24-1-0500-001-1-TS
    supplier: '<a href="https://www.digikey.com/">Digikey</a>'
    spn: CN119B-50-ND
    image:
      src: ./img/1175.jpg
      width: 200       # range: 1~65535; unit: points
      height: 200      # range: 1~65535; unit: points     

connections:
  -
    # non-sequential wiring:
    - J1: [33,34,31,32,29,30,27,28,25,26,23,24,21,22,19,20,17,18,15,16,13,14,11,12,9,10,7,8,5,6,3,4,1,2]
    - W1: [1-34]
    - X1: [1-34]
    
tweak:
  override:
    graph:
      ranksep: '5' # Larger horizontal separation between nodes    

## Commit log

2025-10-09 Project init
    Porting over design from 'Other' Cad software.
    [Lark.kicad_pcb, Lark.kicad_sch, Motor.kicad_sch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]
2025-10-10 still porting design over from 'other' cad software.
    [Boot_Controller.kicad_sch, Buffers.kicad_sch, FTP-68EMCL_Connector.kicad_sch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]
2025-10-10 Added Front pannel IO Sheet
    - added new Molex connector to project lib.
    [FrontIO.kicad_sch, Lark.kicad_sch]
2025-10-11 added power section to schematic
    It needs revised, due to thermal issue. Specifically in regards to my soft start circuit, the mosfet wont be able to handle the power dissipated during a slow turn on.
    [Auxiliary.kicad_sch, Boot_Controller.kicad_sch, Buffers.kicad_sch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]
2025-10-11 update, WIP
    - Reannotated schematic.
    - Added STM32 device.
    - Fixed High-side switch (removed soft-start cap for device safety).
    [Auxiliary.kicad_sch, Boot_Controller.kicad_sch, Buffers.kicad_sch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]
2025-10-11 Updated schematic, WIP
    - Added NOR flash part.
    - Added new CubeMX config file.
    - Reannotated the schematic.
    - Made some more connections to the MCU.
    [Auxiliary.kicad_sch, Boot_Controller.kicad_sch, Buffers.kicad_sch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]
2025-10-12 Update, WIP
    - Added TVS diode to 24v Supply.
    - Fixed bleeder circuit at some point (I think it was this commit)
    - Added Jumper to connect NTC to ADC. (again I think it was this commit)
    [Auxiliary.kicad_sch, Boot_Controller.kicad_sch, Buffers.kicad_sch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]
2025-10-12 End Of Day Commit.
    nothing worth noting, I think I moved a part or two, no major changes.
    [Flash.kicad_sch, MCU.kicad_sch]
2025-10-13 updated WIP
    - fixed high-side switch (swapped out pfets)
    - swapped out bleeder fet.
    - changed a few footprints.
    - changed zeners to 15v ones
    - added soft-start cap back in to the high-side switch.
    (today ive mainly been struggling with the inrush current, but I think its solved now)
    [Auxiliary.kicad_sch, Boot_Controller.kicad_sch, Buffers.kicad_sch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]
2025-10-14 started on layout, WIP
    I'm not a fan of how its going, I feel like I might redo it, before I get to far into it. A patchy foundation makes an unstable house.
    [Buffers.kicad_sch, FTP-68EMCL_Connector.kicad_sch, FrontIO.kicad_sch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]
2025-10-14 Delete Lark.kicad_dru
    dru was empty, so i deleted it.
2025-10-14 updated layout
    got all the control signals routed finally.
    [MCU.kicad_sch]
2025-10-15 The right side of the board is finalized.
    - Finalized the logic side of the board (right)
    - Will work on the power section next.
    [Lark.kicad_sch, MCU.kicad_sch, USB.kicad_sch]
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2025-10-15 Working on power section.
    I have the stuff blocked out, but I'm not liking the layout.
    - changed diode and inductor footprints, adjusted margins.
    [Power.kicad_sch]
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2025-10-16 Finishing up the layout, WIP
    - Changed USBC footprint silkscreen.
    - Routed Power Section.
    - Switched from 7A to 10A Fuse.
    [Power.kicad_sch]
2025-10-17 minor updates
    - changed npn pins to passive.
    - changed rev to match working revision.
    - minor PCB changes.
    - moved TVS diode next to connector.
    - changed barrel jack silkscreen.
    - changed usbc silkscreen.
    [Auxiliary.kicad_sch, Boot_Controller.kicad_sch, Buffers.kicad_sch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]
2025-10-17 Changed revision again...
    - It dawned on me that this is rev 2, so the rev is now 01.00.1.
    - Added thermal relief to the TH pads so I can actually solder the parts.
    - Added more silkscreen to denote the rev, the github link, and ESD sensitivity of the device.
    - Made minor pcb changes, I moved a test point, and cleaned up some traces.
    [Auxiliary.kicad_sch, Boot_Controller.kicad_sch, Buffers.kicad_sch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]
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2025-10-18 Created Front IO Breakout.
    - Needed for testing and diagnostics.
    [FrontIO.kicad_pcb, FrontIO.kicad_sch]
2025-10-18 Created STLink Adapter PCB
    - changed silk on FrontIO PCB a little.
    [Adapter.kicad_pcb, Adapter.kicad_sch, FrontIO.kicad_pcb]
2025-10-19 backup, WIP.
    - So far i think i have everything the way i want it. I'm going to take another few days to look over everything before i finalize the PCB's
2025-10-19 changed dir structure
    [Adapter.kicad_pcb, Adapter.kicad_sch, Auxiliary.kicad_sch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]
2025-10-19 created a demo case for bench testing.
    - The goal is to protect the hardware during testing, to do that, I created a simple case.
2025-10-20 Added Notes
    - Changed AUX power to FAN power, added note about fan.
    - Changed bottom and top silk.
    - Added 24v pour to the top of connector j4, the mid 24v pins remain the same.
    [Auxiliary.kicad_sch]
2025-10-20 Update Demo Case.zip
    - Updated case design.
    - Added more fillets.
    - At some point I added a honey comb pattern, can't remember when.
    - Files in zip are "FAB Ready". Again this is a demo case, the OEM board should be placed in a propper housing when in use.
2025-10-22 Created a housing for the mech unit.
    I need something to mount to mech unit to. It should be cheap to 3D print, at some point I will place an order for one. Note, this is no an injection molded part, it was designed to be resin printed.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
2025-10-22 Added gerbers + bill of materials
    - Changed connector symbol to include MPN.
    - Added DNP field to lark BOM
    [Adapter.kicad_sch, Lark.csv, bom.csv]
2025-10-22 updated git ignore
    - added the schematic QR code to image folder for reference.
2025-10-22 added cad renders from fusion360.
    - I decided to render the assemblies for visual reference.
    - I also included a few exploded assembly views for reference.
    - Used AI to add a cute little Lark to the Mech Assy, I'm calling it the money shot, because it looks golden.
2025-10-22 Added References Docs
    - Added component app notes.
    - Added white papers.
    - Added calculator and other apps source code (relevant to hardware).
    - Added Wiring diagram for the mech connector.
    - Added various Lark project logos (AI generated).
    - Added NON-NDA mech datasheet.
    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
    [Lark.bom.csv, Lark.bom.tsv]
2025-10-22 added schematic pdfs to production files sub directories
    - Added PDF schematics to the production files directory
    - Did not include part placement files, as I am hand assembling the PCB's. However you should be able to generate them from kicad manually with the supplied project files.
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2025-10-23 fixed strobe timing image in schematic, now active low, as it should be
    [FTP-68EMCL_Connector.kicad_sch]
2025-10-23 Update DSView-251023-170413.png
    inverted image for better visibility in the schematic.
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2025-10-25 fixed issue with ADC, Rev-ed board.
    Turns out, you can in fact set PB5 to analog, but its use is with I2C1_SMBA, not the ADC, So I changed it to pin PA3. This renders the head temp functionality on revision 01.00.1 null.
    [Auxiliary.kicad_sch, Boot_Controller.kicad_sch, Buffers.kicad_sch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]
2025-10-25 Update CubeMX_Lark.ioc
    changed ioc, it should now have the correct pinout for REV 01.00.02.
    [CubeMX_Lark.ioc]
2025-10-26 added rev 01.00.02 gerbers to repo.
    [bom.csv]
2025-10-29 updated broken QR on Front IO PCB and SCH.
    [FrontIO.kicad_pcb, FrontIO.kicad_sch]
2025-10-29 updated broken QR code in adapter SCH
    - the site i used to gen the QR codes was a subscription site that generated tiny urls. My trial ran out so now all my QR codes are broken.
    [Adapter.kicad_sch]
2025-10-29 Replaced all broken QR coded in SCH and PCB
    - See previous commit for a detailed explanation of the QR code oversight.
    [Auxiliary.kicad_sch, Boot_Controller.kicad_sch, Buffers.kicad_sch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]
